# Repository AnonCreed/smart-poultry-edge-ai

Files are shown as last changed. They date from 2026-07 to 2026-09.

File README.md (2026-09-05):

# Edge-AI Based Predictive Closed Control System for Smart Poultry Farming






**Minor Project** -- Department of Electronics and Computer Engineering,
Thapathali Campus, Institute of Engineering (IOE), Tribhuvan University.
Submitted in partial fulfillment of the Bachelor's degree in Electronics,
Communication and Information Engineering (August 2026), under the
supervision of **Er. Anup Shrestha**, by Amir Bhattarai, Aviral Adhikari,
Balram Sharma Kandel, and Bikash BK.

## About

Poultry farming is a major part of Nepal's agricultural sector, and most
farms still run open-house systems where the indoor environment tracks
whatever the weather outside is doing. During the brooding stage (the first
two weeks after hatching) chicks are especially sensitive to temperature
swings, humidity, and ammonia buildup from droppings -- conditions farmers
today mostly manage by manual observation and experience, which means
unfavorable changes can go unnoticed until they've already hurt the flock.

This project came out of discussions around the bird-flu outbreaks in Nepal
in 2026. Actually detecting or preventing disease was out of scope for a
minor project, but keeping a poultry house's environment inside a safe band
is a problem we could tackle directly: continuous IoT sensing, an on-device
ML model that forecasts where temperature and ammonia are heading (not just
where they are), and automated fan/heater control that reacts before a
threshold is crossed rather than after.

That's what this repository is: the full system, not just the dashboard --

- **`hardware/esp32/`** -- an ESP32 sensor node reading temperature, humidity
  and ammonia (DHT11 + MQ-137), driving the fan/heater relays.
- **`hardware/esp32s3_master/`** -- an ESP32-S3 master node that receives
  those readings over ESP-NOW and runs an on-device TFLite Micro model to
  forecast the next reading and flag an ammonia-spike probability, before
  handing everything to the backend.
- **`hardware/kicad/`** -- the KiCad schematic and PCB for the sensor node.
- **`telemetry/`** -- the Django backend: ingestion API, server-side rule
  classifier, and the live dashboard (charts, actuator control, console
  feed, historical export).
- **`docs/`** -- the written report and the proposal/final defense decks
  submitted for the degree.

See [Documentation & Reports](#documentation--reports) for the full report
and defense decks, and [Designs](#designs) for the PCB.

## System at a glance

Django backend, Edge-AI-ready JSON REST API, server-side environmental
classifier, a two-board ESP-NOW hardware pipeline (ESP32 sensor node +
ESP32-S3 master node running an on-device TFLite Micro forecast/spike
model), a standalone sensor simulator for development without hardware, and
a standard Bootstrap 5 dashboard (dual-line forecast charts, actuator
control, live console feed, historical reports/CSV export; Bootstrap and
Chart.js are both vendored locally for air-gapped operation).

## Architecture

```
sensor_simulator.py  ──HTTP POST──>  /api/telemetry/submit/
   (Virtual sensor,                     │ validate -> classify -> persist
    5 s cadence,                        ▼
    random walk +               PoultryTelemetry (SQLite, indexed timestamp)
    anomaly injection)                  │
                                        ▼
dashboard (browser)  ──HTTP GET──>  /api/telemetry/historical/?hours=N
   (5 s polling loop feeds metrics grid, charts, audit log)
```

Physical hardware replaces the simulator with a two-board pipeline (the
Django/dashboard side above is unchanged either way):

```
hardware/esp32/ (DevKit V1, sensor node)  --ESP-NOW-->  hardware/esp32s3_master/ (ESP32-S3, master node)
   DHT11 + MQ-137 + fan/heater                     TFLite Micro forecast + spike model
              ^                                              |
              `------------ ESP-NOW (classification) <-------'  --WiFi/HTTP--> /api/telemetry/submit/
```

The master node is the only board that talks to Django; the sensor node only
ever exchanges fixed-size binary structs with the master over ESP-NOW. See
`hardware/esp32/README.md` and `hardware/esp32s3_master/README.md` for the full pipeline,
wiring, and the MAC-address pairing procedure the two boards need before
they can talk to each other.

| Component | Path |
|---|---|
| Data model + classification enum | `telemetry/models.py` |
| Pure classifier decision framework + spike-risk threshold | `telemetry/classifier.py` |
| API views (submit / historical) + dashboard shell | `telemetry/views.py` |
| URL map | `telemetry/urls.py`, `config/urls.py` |
| Virtual sensor client (dev/demo, no hardware needed) | `sensor_simulator.py` |
| ESP32 sensor-node firmware (DHT11 + MQ-137, ESP-NOW, actuator loop) | `hardware/esp32/src/main.cpp`, `hardware/esp32/include/config.h` |
| ESP32-S3 master-node firmware (ESP-NOW receive, TFLite Micro inference, WiFi/HTTP to Django) | `hardware/esp32s3_master/src/main.cpp`, `hardware/esp32s3_master/include/config.h` |
| Dashboard template | `telemetry/templates/telemetry/dashboard.html` |
| Console stylesheet / client runtime | `telemetry/static/telemetry/dashboard.css`, `dashboard.js` |
| Unit tests (classifier + API + forecast + spike-risk contracts) | `telemetry/tests.py` |

## Classifier rules (first match wins)

1. `ammonia_level > 15.0` -> `CRITICAL_AMMONIA` (dark red background, white text)
2. `temperature > 35.0` (live reading OR the Edge-AI forecast alone) -> `HEAT_STRESS_WARNING` (orange border, orange text) -- no humidity condition
3. `temperature < 18.0` -> `LOW_TEMP_ALERT` (deep blue text, light blue accents)
4. otherwise -> `OPTIMAL_ENVIRONMENT` (charcoal grid, solid green indicator dot)

Classification is computed server-side at ingestion, before the INSERT, so every
stored row is complete and immutable. Thresholds are exposed in the historical
API response so the front end never hardcodes them.

## API

`POST /api/telemetry/submit/`
```json
{
  "temperature": 29.4,
  "humidity": 61.2,
  "ammonia_level": 8.7,
  "predicted_temperature": null,
  "predicted_ammonia": null,
  "predicted_spike_probability": null
}
```
Returns `201` with the persisted record including `predicted_class`.

Forecast channels (`predicted_temperature`, `predicted_ammonia`,
`predicted_spike_probability`) are optional and nullable: absent key, explicit
null, and numeric value are all accepted, since the ESP32-S3 master node may not
be linked yet. When numeric, `predicted_temperature`/`predicted_ammonia` are
bounds-checked against the same physical envelope as their live counterparts,
and `predicted_spike_probability` (the master's TFLite Micro spike-classifier
output) is bounds-checked to `[0, 1]`. All three serialize back as JSON null
when absent, so chart clients can rely on key presence. Classification is
always driven by live readings only; forecasts and spike risk are advisory
overlays. Payloads with missing live fields, non-numeric values, or readings
outside physical/probability envelopes are rejected with `400`.

`GET /api/telemetry/historical/?hours=24`
Returns records in the trailing window, ascending chronologically, plus the active
threshold set — ready for direct ingestion by chart libraries.

## Running the system

Two terminals.

Terminal 1 — backend and dashboard:
```bash
pip install -r requirements.txt
python manage.py migrate
python manage.py runserver 0.0.0.0:8000
# Dashboard (this machine):  http://127.0.0.1:8000/
# Dashboard (other devices, e.g. a phone on the same WiFi): http://<this-machine's-LAN-IP>:8000/
```

Binding `0.0.0.0` (not the default `127.0.0.1`) matters if you're using the
physical ESP32-S3 master node -- it needs to reach this over WiFi, and it
finds the LAN IP itself via UDP broadcast discovery (see
`hardware/esp32s3_master/README.md`), so there's no IP to hardcode on either
side. `ALLOWED_HOSTS` is left open (`"*"`) in `config/settings.py` for the
same reason -- this is a dev-only server, never expose it beyond a trusted
LAN.

Terminal 2 — virtual sensor:
```bash
python sensor_simulator.py
# Edge-AI forecast emulation is ON by default so the KPI forecast lines,
# dashed chart series, console (Pred: ...) markers, and the AI spike-risk
# card all have live numbers. To transmit null forecasts/spike-risk
# (matching the deployment state before the ESP32-S3 master node is linked):
python sensor_simulator.py --no-edge-ai
```

The simulator transmits every 5 seconds using an Ornstein-Uhlenbeck-style random
walk (Gaussian step + mean reversion) per channel, and superimposes two anomaly
generators: a triangular thermal spike exceeding 37 C every 2 minutes, and an
ammonia accumulation ramp that climbs past 30 PPM until a simulated ventilation
fan engages and extracts it back to baseline.

## Tests

```bash
python manage.py test telemetry
```

Covers classifier rule precedence (ammonia dominance, heat-stress from live
reading or forecast alone, low-temperature boundary), ingestion validation,
nullable forecast-channel contracts (absent key, explicit null, populated,
invalid type), and historical ordering/threshold contracts.

## Hardware firmware (two boards: ESP32 sensor node + ESP32-S3 master node)

Two firmware projects ship the physical pipeline; both must be flashed and
paired (by MAC address) for the hardware to work end-to-end.

- **`hardware/esp32/`** -- ESP32 DevKit V1 sensor node. Reads DHT11 on GPIO4 and
  MQ-137 on GPIO34 every 5 s, and sends the readings over **ESP-NOW** to the
  master node (no HTTP, no JSON on this board). Drives an ON/OFF fan relay
  (GPIO32) and an ON/OFF heater relay (GPIO25) from the classification the
  master relays back. See `hardware/esp32/README.md` for the pin map and
  MQ-137 calibration
  procedure.
- **`hardware/esp32s3_master/`** -- ESP32-S3 master node. Receives sensor readings
  over ESP-NOW, runs an on-device TFLite Micro model to forecast the next
  temperature/ammonia reading and an ammonia-spike probability, then POSTs
  the combined record to Django using the same JSON contract the Python
  simulator uses. Relays Django's classification back to the sensor node
  over ESP-NOW. See `hardware/esp32s3_master/README.md` for the model details, the
  Arduino IDE flashing steps, and the MAC-pairing procedure required before
  either board can talk to the other.

Quickstart (flash the master first -- you need its printed MAC address to
configure the sensor node):
```bash
cd hardware/esp32s3_master
# Arduino IDE: install libraries per README.md, edit config_master.h
# (WIFI_SSID, WIFI_PASSWORD, API_BASE_URL, SENSOR_NODE_MAC_ADDR),
# then upload esp32s3_master.ino and note the printed "Receiver MAC".

cd ../esp32
# Edit include/config.h: WIFI_SSID, WIFI_PASSWORD (same network as the
# master), MASTER_MAC_ADDR (from the step above).
pio run                 # Compile
pio run -t upload       # Flash over USB
pio device monitor      # Serial diagnostics at 115200 baud
# Copy this board's printed MAC back into hardware/esp32s3_master/config_master.h's
# SENSOR_NODE_MAC_ADDR and reflash the master.
```

The virtual simulator and the physical firmware pipeline are contract-
compatible: both ultimately POST the same JSON payload shape to Django, so
the backend and dashboard cannot tell them apart. The Python simulator
remains useful for CI, demos, and development without hardware in the loop.

## Views

Two tab-switched views share a single polling loop, so the console tail
accumulates in the background even while the user is on the Overview.

### Overview Dashboard
- KPI cards: instantaneous readings with desaturated state accents (colored
  value text plus a 2px left-border highlight; backgrounds stay untouched).
  Each forecastable channel shows a muted secondary line beneath the primary
  value: `AI Forecast: 27.8 degC`, `AI Forecast: 8.4 ppm`. When the ESP32-S3
  master node's link is inactive the line reads `AI Forecast: pending`.
- **AI spike risk** card: the ESP32-S3 master node's TFLite Micro spike-
  classifier probability, rendered as a percentage. Escalates
  ok -> warn -> crit as the probability crosses the calibrated threshold
  (echoed from the API, never hardcoded twice) and twice that threshold.
  Reads `Master node: pending` until the master node is linked.
- Dual-line charts (full vertical breathing room): solid stroke for live
  sensor data, dashed light stroke for Edge-AI forecasts (`spanGaps: false`,
  so null forecast points render as gaps and a fully-null channel is simply
  invisible while remaining mounted), plus a dashed threshold baseline.

### System Logs Feed
Dedicated full-page console. Append-only tail keyed by record id; each new
ingestion appends one line in the format
`[YYYY-MM-DD HH:MM:SS] INGESTION SUCCESS -> T: 27.4C (Pred: 27.8C) | RH: 60.2% | NH3: 8.1ppm (Pred: 8.4ppm) | STATE: OPTIMAL | SPIKE_RISK: 14%`
with text tinted by classification. When a forecast channel is null the
inline marker reads `(Pred: n/a)`; the `SPIKE_RISK` segment is omitted
entirely (not `n/a`) when the master node hasn't reported a probability yet.
Includes a rolling 200-line buffer and a pause-scroll control. The server
emits the same line via the `telemetry.ingest` logger, so `journalctl` and
the browser can be cross-referenced without translation.

## Designs

KiCad schematic + PCB for the ESP32 sensor node live in `hardware/kicad/`
(`kicad.kicad_pro`, `.kicad_sch`, `.kicad_pcb`, `.kicad_prl` -- open the
`.kicad_pro` in KiCad 9). It lays out the ESP32 DevKit V1 footprint alongside
the DHT11, MQ-137, fan/heater relay drive, and terminal-block wiring
described in `hardware/esp32/README.md`.

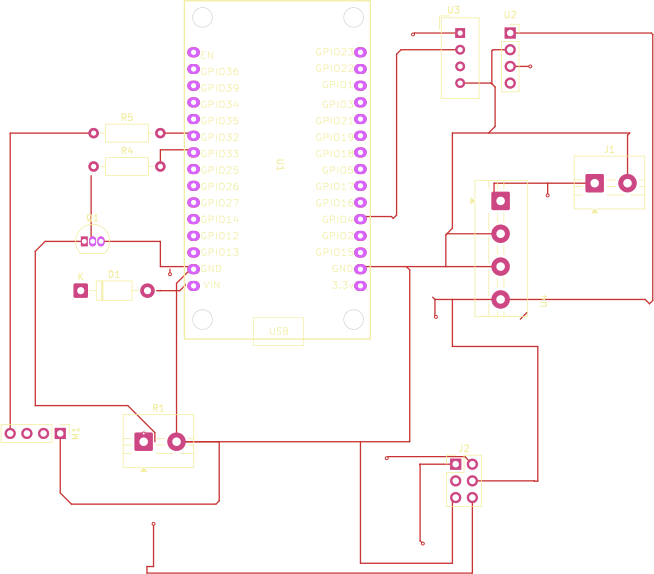
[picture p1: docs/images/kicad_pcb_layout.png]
KiCad PCB top-copper layout


## Documentation & Reports

| Document | Path |
|---|---|
| Minor project report (full, 81 pages) | [`docs/minor_project_report.pdf`](docs/minor_project_report.pdf) |
| Proposal presentation | [`docs/presentations/proposal_presentation.pdf`](docs/presentations/proposal_presentation.pdf) |
| Final defense presentation | [`docs/presentations/final_presentation.pdf`](docs/presentations/final_presentation.pdf) |
| Hardware & firmware architecture deep-dive | [`HARDWARE_DOCUMENTATION.md`](HARDWARE_DOCUMENTATION.md) |

## Team

| Name | Roll No. |
|---|---|
| Amir Bhattarai | THA080BEI005 |
| Aviral Adhikari | THA080BEI011 |
| Balram Sharma Kandel | THA080BEI012 |
| Bikash BK | THA080BEI015 |

Supervised by **Er. Anup Shrestha**, Department of Electronics and Computer
Engineering, Thapathali Campus, Institute of Engineering, Tribhuvan University.

## License

MIT -- see [`LICENSE`](LICENSE).

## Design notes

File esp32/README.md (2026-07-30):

# ESP32 Sensor Node -- Firmware

Production-grade Arduino/ESP32 firmware for the Poultry Telemetry sensor
node. Reads DHT22 (temperature + humidity) and MQ-137 (ammonia PPM) every
5 seconds and sends them over **ESP-NOW** to the ESP32-S3 master node
(`../esp32s3_master/`), which runs the on-device forecast/spike model and
owns the WiFi/HTTP leg to Django. The master relays Django's classification
back over ESP-NOW so this board can still drive its own fan and heater PWM
outputs, closing the control loop end-to-end across the two boards.

This board still joins WiFi (see `include/config.h`), but only to (a) land
on the same channel as the master -- ESP-NOW requires both peers on the
same channel, and joining the same AP is the simplest way to guarantee that
-- and (b) sync wall-clock time over NTP for the model's hour/month cyclic
features. It no longer POSTs to Django directly; see
`../esp32s3_master/README.md` for the full two-board pipeline and the MAC
pairing procedure required before either board can talk to the other.

## Pin map (must match the KiCad schematic)

| Signal | GPIO | Socket pin | Notes |
|---|---|---|---|
| `DHT_DATA` | GPIO4  | 20 | 10 kOhm pull-up to 3V3; single-wire DHT22 protocol |
| `MQ_DATA` | GPIO34 | 12 | INPUT-ONLY, ADC1_CH6 -- required so WiFi and ADC coexist |
| `PWM_FAN` | GPIO32 | 10 | LEDC ch 0, 25 kHz -- gate driven through R5 = 200 Ohm |
| `PWM_HEATER`  | GPIO33 | 9 | LEDC ch 1, 25 kHz -- gate driven through R4 = 200 Ohm |
| `VIN` (+5V) | - | 1 | USB or external 5 V bench supply |
| `GND` | - | 2 / 17 | Common ground with sensor and actuator returns |
| `3V3` | - | 16 | Sensor Vcc supply |

Two constraints are non-negotiable:

1. **MQ-137 output must be scaled to 0-3.3 V before reaching GPIO34.** MQ
   modules commonly swing to 5 V; feeding that directly into any ESP32 pin
   damages the SoC. Use an on-module divider or add an external 1:2 divider
   (e.g. 10 kOhm / 20 kOhm to GND).
2. **GPIO34 is input-only.** It has no internal pull-ups and cannot be an
   output. Any attempt to move `MQ_DATA` to a different pin also invalidates
   the "ADC1 while WiFi is active" guarantee -- ADC2 channels are unusable
   during WiFi association.

## Build and flash

```bash
cd esp32
# Edit include/config.h: WIFI_SSID, WIFI_PASSWORD, MASTER_MAC_ADDR
# (see the MAC pairing procedure in ../esp32s3_master/README.md), and
# GMT_OFFSET_SEC for your timezone.
pio run                 # Compile
pio run -t upload       # Flash over USB
pio device monitor      # Serial console at 115200 baud
```

Flash the ESP32-S3 master (`../esp32s3_master/`) first so you have its MAC
address to put in `MASTER_MAC_ADDR` before flashing this board.

Alternatively in the Arduino IDE: open `src/main.cpp` as `main.ino` (or copy
into a sketch with the same name as the folder), install the two libraries
listed in `platformio.ini` (ESP-NOW ships with the esp32 board package, no
separate library needed), and select "ESP32 Dev Module".

## MQ-137 calibration

The datasheet curve fit ships in `config.h` (`MQ137_A = 102.2`, `MQ137_B =
-2.473`), but `MQ137_R0_KOHMS` **must be recalibrated per unit** after a 24-48
hour burn-in:

1. Power the sensor continuously in known-clean outdoor air for at least 24 h.
2. Read the averaged Rs value from the serial log (raw `[MQ] Rs=...` line
   after uncommenting the diagnostic printf near `mqCountsToPpm`).
3. Set `MQ137_R0_KOHMS` to that value.
4. Reflash.

Without this step the reported PPM has a per-unit multiplicative error that
can easily reach 3-5x. The classifier threshold (25 PPM CRITICAL) is set
against calibrated readings, so uncalibrated sensors will either false-alarm
or, worse, miss real breaches.

## Control loop

The master node POSTs each record to Django, which classifies it and
returns `record.predicted_class`. The master relays that string back to
this board over ESP-NOW (`ActuatorCommand`), and the firmware maps it to
actuator state:

| Classification | Fan  | Heater |
|---|---|---|
| `CRITICAL_AMMONIA` | ON | OFF |
| `HEAT_STRESS_WARNING` | ON | OFF |
| `LOW_TEMP_ALERT` | OFF  | ON |
| `OPTIMAL_ENVIRONMENT` | OFF  | OFF |

The interlock (fan and heater never both on) is inherent to the
classification -- a single state is returned per record.

## Edge-AI forecast and spike-risk prediction

This board no longer computes a forecast itself -- the on-node linear-
extrapolation stub from earlier versions has been superseded by the ESP32-S3
master's real TFLite Micro model, which produces `predicted_temperature`,
`predicted_ammonia`, and `predicted_spike_probability` from a rolling window
of this board's raw readings. See `../esp32s3_master/README.md` for the
model details and the spike-risk threshold.

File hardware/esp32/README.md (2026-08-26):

# ESP32 Sensor Node -- Firmware

Production-grade Arduino/ESP32 firmware for the Poultry Telemetry sensor
node. Reads DHT11 (temperature + humidity) and MQ-137 (ammonia PPM) every
5 seconds and sends them over **ESP-NOW** to the ESP32-S3 master node
(`../esp32s3_master/`), which runs the on-device forecast/spike model and
owns the WiFi/HTTP leg to Django. The master relays Django's classification
back over ESP-NOW so this board can still drive its own fan (PWM speed
control) and PTC heater (ON/OFF relay -- see `HEATER_RELAY_ON`/`_OFF` in
`include/config.h` for this board's relay polarity), closing the control
loop end-to-end across the two boards.

This board has **no WiFi at all** -- no credentials, no AP join, no IP, no
NTP. It only brings the radio up to speak ESP-NOW directly to the master,
on a fixed channel set at compile time (`ESPNOW_WIFI_CHANNEL`,
`include/config.h`) since there's no AP association to inherit a channel
from. See `include/config.h`'s "Radio" section for why the channel is
fixed rather than negotiated, and what to do if it ever needs to change.
This board never talks to Django directly either; see
`../esp32s3_master/README.md` for the full two-board pipeline and the MAC
pairing procedure required before either board can talk to the other.

## Pin map (must match the KiCad schematic)

| Signal | GPIO | Socket pin | Notes |
|---|---|---|---|
| `DHT_DATA` | GPIO4  | 20 | 10 kOhm pull-up to 3V3; single-wire DHT11 protocol |
| `MQ_DATA` | GPIO34 | 12 | INPUT-ONLY, ADC1_CH6 -- required so WiFi and ADC coexist |
| `PWM_FAN` | GPIO32 | 10 | LEDC PWM (channel 0, 25 kHz, 8-bit) speed target to the fan's own driver IC -- not a power switch, see `FAN_ENABLE` below |
| `FAN_ENABLE`  | GPIO27 | TBD -- verify against schematic | Digital output gating an external N-MOSFET on the fan's GND leg; HIGH = fan powered, LOW = de-energized. Real hard-off, since many cheap fans don't honor 0% PWM duty as a true stop |
| `HEATER_RELAY`| GPIO25 | TBD -- verify against schematic | Digital output to relay module IN pin; HIGH = heater ON, LOW = OFF (`HEATER_RELAY_ON`/`_OFF` in `config.h` -- confirmed by bench test 2026-08-23, opposite of the module's original active-LOW assumption). ON/OFF only, no speed control |
| `LCD_SDA` | GPIO21 | TBD -- verify against schematic | I2C data to the LCD's PCF8574T backpack. ESP32 DevKit V1 hardware I2C default |
| `LCD_SCL` | GPIO22 | TBD -- verify against schematic | I2C clock to the LCD's PCF8574T backpack. ESP32 DevKit V1 hardware I2C default |
| `VIN` (+5V) | - | 1 | USB or external 5 V bench supply; also feeds the LCD's VCC |
| `GND` | - | 2 / 17 | Common ground with sensor and actuator returns, and the LCD |
| `3V3` | - | 16 | Sensor Vcc supply |

Two constraints are non-negotiable:

1. **MQ-137 output must be scaled to 0-3.3 V before reaching GPIO34.** MQ
   modules commonly swing to 5 V; feeding that directly into any ESP32 pin
   damages the SoC. Use an on-module divider or add an external 1:2 divider
   (e.g. 10 kOhm / 20 kOhm to GND).
2. **GPIO34 is input-only.** It has no internal pull-ups and cannot be an
   output. Any attempt to move `MQ_DATA` to a different pin also invalidates
   the "ADC1 while WiFi is active" guarantee -- ADC2 channels are unusable
   during WiFi association.

## Build and flash

```bash
cd hardware/esp32
# Edit include/config.h: MASTER_MAC_ADDR (see the MAC pairing procedure in
# ../esp32s3_master/README.md) and ESPNOW_WIFI_CHANNEL if your router isn't
# on channel 1. No WiFi credentials to set -- this board has none.
pio run                 # Compile
pio run -t upload       # Flash over USB
pio device monitor      # Serial console at 115200 baud
```

Flash the ESP32-S3 master (`../esp32s3_master/`) first so you have its MAC
address to put in `MASTER_MAC_ADDR` before flashing this board.

Alternatively in the Arduino IDE: open `src/main.cpp` as `main.ino` (or copy
into a sketch with the same name as the folder), install the two libraries
listed in `platformio.ini` (ESP-NOW ships with the esp32 board package, no
separate library needed), and select "ESP32 Dev Module".

## MQ-137 calibration

The datasheet curve fit ships in `config.h` (`MQ137_A = 102.2`, `MQ137_B =
-2.473`), but `MQ137_R0_KOHMS` **must be recalibrated per unit** after a 24-48
hour burn-in:

1. Power the sensor continuously in known-clean outdoor air for at least 24 h.
2. Read the averaged Rs value from the serial log (raw `[MQ] Rs=...` line
   after uncommenting the diagnostic printf near `mqCountsToPpm`).
3. Set `MQ137_R0_KOHMS` to that value.
4. Reflash.

Without this step the reported PPM has a per-unit multiplicative error that
can easily reach 3-5x. The classifier threshold (15 PPM CRITICAL) is set
against calibrated readings, so uncalibrated sensors will either false-alarm
or, worse, miss real breaches.

## Control loop

The master node POSTs each record to Django, which classifies it and
returns `record.predicted_class`. The master relays that string back to
this board over ESP-NOW (`ActuatorCommand`), along with **two independently
computed bytes**: `fan_pwm` (0-255, from its on-device model's
predicted-NH3 error) and `heater_pwm` (0-255, from the classification --
`LOW_TEMP_ALERT` -> 255, else 0). A dashboard MANUAL override, if set,
replaces *both* bytes with the operator's fan speed % / heater power %
before they're sent. This board makes no actuation decisions of its own any
more -- it only applies whatever the master sends:

| Signal | Fan (PWM) | Heater relay |
|---|---|---|
| `fan_pwm` | Written verbatim as PWM duty (0-255) | -- |
| `fan_pwm > 0` | `FAN_ENABLE` driven HIGH (powered) | -- |
| `fan_pwm == 0`  | `FAN_ENABLE` driven LOW (de-energized) | -- |
| `heater_pwm > 0`| -- | ON (relay energized) |
| `heater_pwm == 0`| -- | OFF (relay de-energized) |

**Note:** earlier revisions of this board guaranteed fan and heater were
never both ON, since a single classification string drove both locally.
That guarantee no longer holds -- `fan_pwm` and `heater_pwm` are computed
independently on the master (and either can come from a MANUAL dashboard
override, decoupled from the other), so e.g. a nonzero MANUAL fan override
alongside a nonzero heater_pwm (MANUAL or `LOW_TEMP_ALERT`-driven) will run
the fan and energize the heater relay simultaneously. If that combination is
unsafe for the physical setup, it needs to be enforced explicitly (either
server-side in the dashboard/master's `loop()`, or by forcing `fan_pwm` to 0
in this board's `applyActuators()` whenever `heaterOn` is true) -- it is not
currently enforced anywhere in either firmware.

## Edge-AI forecast and spike-risk prediction

This board no longer computes a forecast itself -- the on-node linear-
extrapolation stub from earlier versions has been superseded by the ESP32-S3
master's real TFLite Micro model, which produces `predicted_temperature`,
`predicted_ammonia`, and `predicted_spike_probability` from a rolling window
of this board's raw readings. See `../esp32s3_master/README.md` for the
model details and the spike-risk threshold.

## LCD (I2C 16x2, RG1602A-IIC(P) / PCF8574T backpack)

Wired to the DevKit's hardware I2C bus (`include/config.h`: `PIN_LCD_SDA` =
GPIO21, `PIN_LCD_SCL` = GPIO22; GND to GND, VCC to VIN/5V). Shows a static
two-line readout of this board's own current reading -- no rotation, no
forecast:

- **Row 0** -- current temperature + humidity from the DHT11 (`T:25.3C H:60%`).
- **Row 1** -- current MQ-137 ammonia reading (`NH3: 12.3 ppm`).

Both rows redraw every time a fresh sample completes (`SAMPLE_INTERVAL_MS`,
5 s by default); before the first successful reading they show a boot
placeholder instead. The master still relays back `predicted_temperature`/
`predicted_ammonia`/`has_prediction` on the `ActuatorCommand` wire contract
(see the comment above `struct ActuatorCommand` in `src/main.cpp`) -- this
board receives them but intentionally doesn't display them; the LCD is
current-data-only on this branch.

The backpack answers at I2C address `0x27` by default (`LCD_I2C_ADDR` in
`config.h`); some PCF8574AT clones use `0x3F` instead -- if the display stays
blank after wiring is confirmed correct, run an I2C scanner sketch to find
the real address before assuming a wiring fault. Requires the
`marcoschwartz/LiquidCrystal_I2C` library, pulled automatically via
`platformio.ini`'s `lib_deps`.

## Benchmark mode -- synthetic data for testing the predictive system

`platformio.ini` defines a second environment, `esp32dev_benchmark`, that
replaces this board's real DHT11/MQ-137 reads with a scripted sequence of
scenarios instead -- for exercising the master's on-device predictive model,
Django's classifier, and the real actuator response on-demand and
repeatably, without needing a physical sensor attached or waiting on real
environmental drift to test an edge case. Everything downstream of the
sensor read is the genuine pipeline: real ESP-NOW, real TFLite inference on
the master, real classification, real fan/heater relay -- only the sensor
value itself is synthetic.

```bash
pio run -e esp32dev_benchmark -t upload    # flash the benchmark build
pio device monitor                         # watch [BENCHMARK]/[TX] lines

# ... test, watch the master's [MODEL]/[ACTUATE] lines and the dashboard ...

pio run -e esp32dev -t upload              # flash back to real sensors
```

This is **compile-time only** (`BENCHMARK_MODE`, set via the dedicated
environment's `build_flags`, never a runtime toggle) -- a board can't
accidentally start reporting fake data without an explicit reflash, and both
the boot banner and the LCD say "BENCHMARK MODE" loudly on startup as a
physical reminder while it's active.

The scenario list (`BENCHMARK_SCENARIOS` in `src/main.cpp`) cycles through,
holding or ramping each for `BENCHMARK_SAMPLES_PER_SCENARIO` samples
(`config.h`, default 24 * 5 s = 2 minutes per scenario). **Note:** this
2-minute-per-scenario default predates the current model's retrain -- the
old windowed model warmed up in ~9 samples (~45 s), so 2 minutes was
generous. The retrained model needs 7 finalized 10-minute buckets
(~70 minutes after boot, see `hardware/esp32s3_master/README.md`'s "Model
architecture" section) before it produces its first prediction at all, so
a full benchmark loop now cycles through several scenarios before any
prediction appears. Fine for exercising ESP-NOW/classification/actuation
(none of that depends on warm-up), but if you specifically want to watch
`predicted_ammonia` lead a live reading during `AMMONIA_RAMP_TO_SPIKE`,
either let one scenario hold well past 70 minutes (raise
`BENCHMARK_SAMPLES_PER_SCENARIO` for that run) or just wait out the real
warm-up once and watch subsequent scenarios normally after that.

| Scenario | Tests |
|---|---|
| `OPTIMAL_BASELINE` | Warm-up baseline; nothing should trip. |
| `AMMONIA_STEP_CRITICAL` / `_RECOVER` | Instant step across the 15 ppm `CRITICAL_AMMONIA` threshold, both directions -- classification latency, actuator response speed. |
| `AMMONIA_RAMP_TO_SPIKE` / `_RECOVER` | Gradual rise/fall through the threshold -- does `predicted_ammonia` (the forecast) lead the live reading, and does `predicted_spike_probability` rise before the classifier actually flips? |
| `AMMONIA_BOUNDARY_LOW` / `_HIGH` | Held just under/over 15 ppm -- exact threshold correctness, no off-by-one. |
| `HEAT_STRESS_STEP` / `_RECOVER` | T + RH combined past both thresholds at once (the classifier's conjunction rule) and back. |
| `LOW_TEMP_STEP` / `_RECOVER` | Below 18°C and back -- heater relay reactivity. |
| `COLD_AND_CRITICAL_AMMONIA` / `_RECOVER` | Cold and critical ammonia at once -- `predicted_class` comes back `CRITICAL_AMMONIA` only (classify_environment() checks ammonia first), so this is the regression case for the `low_temperature_alert` fix: both fan **and** heater must activate, not just the fan. |

Add, remove, or edit entries in `BENCHMARK_SCENARIOS` for other cases (a
different profile's thresholds, a slower/faster ramp, a longer soak at one
value) -- each row is just a name plus a start/end value per channel, so a
constant scenario is a step and a `Start != End` scenario is a ramp.

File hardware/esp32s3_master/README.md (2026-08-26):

# ESP32-S3 Master Node -- Firmware

Receives raw sensor samples from the ESP32 DevKit V1 sensor node
(`hardware/esp32/`) over ESP-NOW, runs an on-device TFLite Micro model to forecast
next-tick temperature/ammonia and an ammonia-spike probability, forwards the
combined record to the Django backend, and relays the resulting
classification back to the sensor node so it can drive its own actuators.

```
esp32 (DevKit V1)  --ESP-NOW-->  esp32s3_master (this board)  --WiFi/HTTP-->  Django
   sensors + fan/heater              inference + relay              /api/telemetry/submit/
        ^                                    |
        `------------ ESP-NOW (classification) <----------'
```

Builds with PlatformIO (same toolchain as the sensor node in `hardware/esp32/`).

## Contents

| File | Purpose |
|---|---|
| `src/main.cpp` | ESP-NOW receive, WiFi/HTTP forward to Django, actuator relay. |
| `src/model_runner.cpp` / `include/model_runner.h` | Feature engineering, TFLite Micro inference, output scaling. |
| `include/model_data.h` | Trained TFLite Micro model, flatbuffer byte array. **Trained artifact -- do not hand-edit.** |
| `include/scaler_params.h` | Feature normalization (mean/scale) and the calibrated spike-risk decision threshold. **Trained artifact -- do not hand-edit.** |
| `include/config.h` | Django API port/path, discovery protocol constants, NTP, timing constants. No IP to edit -- see Discovery below. |
| `include/credentials.h` (gitignored, copy from `.example`) | WiFi SSID/password. |

## Model architecture (retrained 2026-08-26)

A bifurcated multi-task MLP (Keras) trained offline against
`poultry_sensor_data_cleaned.csv` (9,708 rows), replacing the earlier
windowed model:

- **Input**: a flat 44-element engineered feature vector -- no on-device
  windowed tensor. The "sliding window" lives entirely in feature
  engineering (pandas `.shift()`/`.rolling()` at training time,
  `buildFeatureRow()` in `model_runner.cpp` on-device): 6 base columns
  (`temperature`, `humidity`, `ammonia_ppm`, `hour_sin`, `hour_cos`,
  `temp_hum_interaction`) x 7 derived values each (`lag1`, `lag2`, `lag3`,
  `lag6`, `roll_mean3`, `roll_std3`, `delta1`) = 42, plus `ammonia_accel`
  (second-order ammonia momentum) and `week` (flock age in weeks, clipped
  to `[1, 5]`) = 44 total. Exact order is fixed by `feature_cols` in the
  training script and mirrored feature-for-feature in `buildFeatureRow()`.
- **Output**: two 2-element heads --
  `next_values` (regression: standardized next-tick temperature and
  log1p-transformed next-tick ammonia, both needing the inverse transform
  in `readPrediction()`) and `spike_flags` (classification: sigmoid
  ammonia-spike and temperature-spike probabilities). TFLite conversion
  does **not** guarantee output tensor order matches the Python
  `outputs=[...]` declaration order -- `readPrediction()` disambiguates at
  runtime via a value-range heuristic (sigmoid outputs stay in `[0, 1]`;
  standardized regression outputs don't), documented in-line with the exact
  verification snippet, with a fallback to the empirically verified fixed
  order if that heuristic is ever ambiguous.
- **Training cadence vs. real sensor cadence**: the training pipeline
  resamples to a fixed 10-minute interval, but the sensor node transmits
  every ~5 s (`SAMPLE_INTERVAL_MS`, matching this project's
  `HARDWARE_DOCUMENTATION.md` / report Section 5.5.6). Feeding raw 5s
  samples straight into "lag1" would silently redefine it from "10 minutes
  ago" to "5 seconds ago" and make every learned weight meaningless.
  `model_runner.cpp` bridges this by averaging incoming samples into a
  rolling 10-minute `Bucket`, finalizing it into a `FinalizedBucket` history
  ring buffer (7 deep -- lag6 reaches 60 min back, plus the current bucket)
  once `kBucketDurationMs` elapses, and computing all lag/rolling/delta
  features only from that finalized-bucket history. Consequence: the first
  real inference doesn't happen until **~70 minutes after boot** (7 buckets
  x 10 min), during which `[MODEL] warming up` prints instead.
- **Export format -- must stay pure float32, not quantized**: an earlier
  export used `tf.lite.TFLiteConverter`'s dynamic-range quantization
  (`converter.optimizations = [tf.lite.Optimize.DEFAULT]`), which produced
  a smaller `.tflite` (~19 KB vs ~49 KB) that ran fine on a desktop
  `tf.lite.Interpreter` but made TFLite Micro's `Invoke()` silently
  overwrite the input tensor with NaN on real hardware -- confirmed by
  Serial-printing the input tensor's values immediately before and after
  `Invoke()` (finite before, all-NaN after), isolating the corruption to
  the embedded kernel's handling of hybrid-quantized `FULLY_CONNECTED`
  weights rather than any host-side bug. Fix: re-export from the saved
  `.keras` model with no `converter.optimizations` set at all. **Any future
  retrain must export the same way** (see below) or this bug reappears.

## Swapping in a retrained model

`model_data.h` and `include/scaler_params.h` are the only files a retrain
should touch -- regenerate both from the training pipeline's
`export_meta.pkl` + the trained `.tflite`, drop them in place of the
existing ones, and rebuild. Nothing else needs to change **as long as the
new model keeps the same 44-feature input layout and the same two
2-element output heads** described above. If the training pipeline ever
changes which features it derives (`feature_cols` in the training script),
`buildFeatureRow()` in `model_runner.cpp` needs matching edits -- everything
else in that file (bucketing, normalization, tensor plumbing) is generic
and doesn't care what the model looks like.

Steps, in order:

1. Retrain and save the Keras model as usual, then export to TFLite
   **without quantization** (see "must stay pure float32" above):
   ```python
   converter = tf.lite.TFLiteConverter.from_keras_model(model)
   # Deliberately no converter.optimizations -- see README for why.
   tflite_model = converter.convert()
   open('model_esp32.tflite', 'wb').write(tflite_model)
   ```
2. Verify the output tensor order didn't shift:
   ```python
   import tensorflow as tf, numpy as np
   interp = tf.lite.Interpreter(model_path='model_esp32.tflite')
   interp.allocate_tensors()
   inp, out = interp.get_input_details(), interp.get_output_details()
   x = np.zeros((1, 44), dtype=np.float32)
   interp.set_tensor(inp[0]['index'], x); interp.invoke()
   for d in out: print(d['name'], '->', interp.get_tensor(d['index']))
   ```
   If the order changed, `readPrediction()`'s runtime heuristic in
   `model_runner.cpp` should still cope automatically -- but double-check
   its documented fallback order comment matches the new result anyway.
3. Verify the op list didn't grow beyond what `init()`'s
   `MicroMutableOpResolver<3>` registers (`FullyConnected`, `Concatenation`,
   `Logistic`):
   ```python
   from tensorflow.lite.python import schema_py_generated as schema_fb
   buf = bytearray(open('model_esp32.tflite', 'rb').read())
   m = schema_fb.ModelT.InitFromObj(schema_fb.Model.GetRootAsModel(buf, 0))
   codes = {(oc.deprecatedBuiltinCode if oc.builtinCode == 0 else oc.builtinCode) for oc in m.operatorCodes}
   names = {v: k for k, v in vars(schema_fb.BuiltinOperator).items() if isinstance(v, int)}
   print([names.get(c, c) for c in codes])
   ```
   A new op means adding the matching `Add*()` call in `init()` and bumping
   the resolver's template argument.
4. Regenerate `model_data.h` as a C byte array from the `.tflite` file
   (standard `xxd -i` / equivalent one-liner), and `scaler_params.h` from
   `export_meta.pkl`'s `feature_mean`/`feature_scale`/`reg_mean`/
   `reg_scale`/`best_thresholds` -- keep the reg/clf ordering comments in
   that file in sync with `reg_targets`/`clf_targets` from the training
   script.
5. Rebuild, reflash, and confirm on Serial that early inferences (after the
   ~70-minute warm-up) are finite and plausible -- not NaN.

## Flashing

1. Install PlatformIO (CLI or the VS Code extension).
2. Copy `include/credentials.h.example` to `include/credentials.h` and fill
   in `WIFI_SSID` / `WIFI_PASSWORD` for this board's own network -- the
   sensor node has no WiFi credentials of its own to match; it never joins
   any AP (see `../esp32/README.md`). ESP-NOW still requires both radios on
   the same WiFi channel, so the sensor node hardcodes a fixed channel
   (`ESPNOW_WIFI_CHANNEL`, `../esp32/include/config.h`) instead -- if this
   board's router ever assigns a different channel than that constant, this
   board logs a boot-time `[WIFI] WARNING` (it can't fix the mismatch
   itself; update the sensor's config.h and reflash it, or fix the
   router's channel).
3. `pio run -t upload` (or use the PlatformIO IDE build/upload buttons),
   then open the serial monitor at 115200 baud. No Django IP to configure --
   see Discovery below.

## Discovery (no hardcoded Django IP)

This board finds the Django host at runtime instead of using a baked-in IP,
so the same firmware image works unmodified on any WiFi network the board
and the Django PC both join:

1. On boot (and again from `loop()` any time the host is unknown), it
   broadcasts a UDP packet to the local subnet's broadcast address on port
   `DISCOVERY_PORT` (`config.h`).
2. `telemetry/discovery.py` on the Django side listens on that same UDP
   port (started automatically by `manage.py runserver`) and replies to
   whoever sent the request.
3. The board reads the reply's **source IP** as the Django host -- not
   the payload -- so no address is ever hand-configured.
4. If POSTs start failing against a previously-discovered host (e.g. the
   Django PC got a new DHCP lease), the board drops it and re-discovers
   automatically after a few consecutive failures.

Requirements: the Django PC and this board must be on the same subnet
(broadcast doesn't cross routers/VLANs), and `python manage.py runserver`
must be bound to `0.0.0.0:8000` (not `127.0.0.1`) so both the HTTP API and
the discovery responder are reachable from the board.

## MAC pairing

Unlike the sensor node, this board doesn't need a MAC address configured up
front -- `onDataRecv()` in `main.cpp` auto-learns the sensor node's MAC from
the first ESP-NOW packet it receives and registers it as a peer so it can
send `ActuatorCommand`s back.

1. Flash this board first. On boot it prints:
   ```
   [BOOT] Master MAC (WiFi STA): AA:BB:CC:DD:EE:FF
   ```
   Copy that into `hardware/esp32/include/config.h`'s `MASTER_MAC_ADDR` on
   the sensor node.
2. Flash the sensor node (`hardware/esp32/`, see its README). No MAC needs
   copying back the other way -- this board learns it automatically.

## Data flow per sample

1. Sensor node sends a `SensorPacket` (temperature, humidity, ammonia_ppm --
   no hour/month; it has no WiFi/NTP to source them from) over ESP-NOW
   every 5 s. This board supplies hour itself from its own NTP sync
   (`currentHour()` in `main.cpp`) for the model's hour-of-day feature.
2. This board averages incoming samples into a rolling 10-minute bucket and
   keeps a 7-bucket finalized history (`model_runner.cpp`) -- see "Model
   architecture" above for why. That history needs to fill before the first
   inference; expect `[MODEL] warming up` lines for the first ~70 minutes
   after boot.
3. Once warmed up, each bucket finalization runs one inference producing
   `predicted_temperature`, `predicted_ammonia`, and
   `predicted_spike_probability` (ammonia-spike probability; the model also
   computes a `temp_spike_probability` but that isn't wired to Django/the
   dashboard yet). While still warming up, the three POSTed fields are
   `null` and Django classifies from live readings alone.
4. That triple, plus the raw reading, POSTs to
   `http://{DJANGO_HOST}:{DJANGO_PORT}{SUBMIT_PATH}` using the same JSON
   contract the Python simulator and Django's ingestion validation already
   expect (see the project root `README.md`).
5. Django's rule-based classification (`predicted_class`) comes back in the
   response and is relayed to the sensor node over ESP-NOW so it can drive
   its fan/heater -- independent of the spike-risk prediction, which is an
   advisory signal only and never itself flips the classification.
6. The same `ActuatorCommand` also carries `has_prediction` +
   `predicted_temperature` + `predicted_ammonia` (the just-computed
   `pred.temperature_next` / `pred.ammonia_next`, or the last cached
   prediction when this send is the independent MANUAL-override poll rather
   than a fresh inference -- see `g_lastPrediction` in `main.cpp`) purely so
   the sensor node's LCD can show a "Predicted" screen. These three fields
   are display-only; no actuation decision reads them back on either board.

## Spike-risk threshold

`scaler_params.h`'s `kAmmoniaSpikeThreshold` is the calibrated cutoff above
which the model's classifier head predicts an imminent ammonia spike (the
model also has a `kTempSpikeThreshold` for the sibling temperature-spike
head, currently used on-device only -- see "Data flow per sample" above).
Django echoes `kAmmoniaSpikeThreshold`'s value as
`ammonia_spike_risk_threshold` in the `/api/telemetry/historical/` response
(`telemetry/classifier.py`'s `AMMONIA_SPIKE_RISK_THRESHOLD`) so the
dashboard never hardcodes a second copy. If the model is ever retrained
with different thresholds, update both places together.

## Sensor silence watchdog

If no `SensorPacket` arrives over ESP-NOW for `SENSOR_SILENCE_TIMEOUT_MS`
(`config.h`, 3x the sensor's 5s `SAMPLE_INTERVAL_MS` -- ~15s), `loop()`
logs `[ESPNOW] No sensor packet in ... -- re-initializing ESP-NOW.` and
re-runs the same `esp_now_deinit()`/`initEspNow()`/`registerSensorPeer()`
recovery sequence already used when this board's own WiFi reconnects (see
`ensureWifi()`). This covers a stuck ESP-NOW stack that didn't involve a
WiFi drop on this board -- distinct from `postToDjango()`'s existing
3-failures-triggers-re-discovery logic, which reacts to failed HTTP POSTs
to Django, not to sensor silence. Cheap and safe to fire repeatedly: it
doesn't touch the model's bucket history, so a real but brief sensor outage
doesn't cost the ~70 minute warm-up. If the sensor node is genuinely
powered off, this just keeps retrying every window until it comes back --
it can't fix a truly-dead sensor by itself, only re-arm this board's own
side of the link in case that was the actual problem.

## Known limitations

- Single sensor node only: the feature/history buffers assume one upstream
  board. Supporting multiple sensor nodes would need per-node history
  buffers and a node-identity field threaded through the ESP-NOW packet,
  Django's model, and the dashboard -- not implemented here.
- No ESP-NOW encryption -- fine on a private/trusted LAN, not for anything
  internet-facing. See `HARDWARE_DOCUMENTATION.md`'s security section for
  the same caveat on the original HTTP-only design.
- If the Django POST fails (network blip, backend restart), that sample's
  classification never reaches the sensor node and its actuators simply
  hold their last commanded state.
- The sensor node hardcodes its ESP-NOW channel instead of negotiating one
  (see "Flashing" above) -- if the router's channel ever changes, ESP-NOW
  silently breaks until `ESPNOW_WIFI_CHANNEL` is updated and the sensor
  node reflashed. This board logs a warning when it detects the mismatch,
  but can't self-heal it (unlike the silence watchdog above, which only
  helps when this board's own ESP-NOW stack -- not the channel itself --
  is the problem).

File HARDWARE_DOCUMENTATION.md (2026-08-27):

# Hardware & Embedded Firmware Architecture Defense Guide

> **Two-board architecture as of the ESP-NOW revision.** The system is now
> two microcontrollers, not one: an **ESP32 DevKit V1 sensor node**
> (`hardware/esp32/`, unchanged hardware, revised firmware) reads DHT11/MQ-137 and
> sends raw samples over **ESP-NOW** to an **ESP32-S3 master node**
> (`hardware/esp32s3_master/`, new), which runs an on-device TFLite Micro model and
> owns the WiFi/HTTP leg to Django. Everything below that describes the
> single-board HTTP pipeline has been updated to describe the sensor node's
> half only; the master node's half is documented where it diverges, and in
> full in `hardware/esp32s3_master/README.md`.

## 1. Stack Overview & Library Analysis
- Microcontroller Hardware: ESP32 DevKit V1 class board (sensor node), selected via board = esp32dev in PlatformIO, plus an ESP32-S3 board (master node) running an Arduino IDE sketch.
- Core Framework: PlatformIO build system with Arduino C++ framework on Espressif32 for the sensor node; Arduino IDE with the same Espressif "esp32" board package for the master node (required by its TensorFlowLite_ESP32 library dependency -- see hardware/esp32s3_master/README.md's "Why Arduino IDE, not PlatformIO").

### Build and Runtime Context
- MCU family: ESP32 (dual-core Xtensa, integrated Wi-Fi, hardware PWM via LEDC, ADC1/ADC2 blocks).
- Firmware environment: [env:esp32dev] in hardware/esp32/platformio.ini.
- Monitor/upload settings:
  - monitor_speed = 115200 (matches Serial.begin(115200)).
  - upload_speed = 921600.
- Build diagnostics:
  - CORE_DEBUG_LEVEL=3 (INFO level logs in ESP core).

### Dependency Breakdown from platformio.ini
1. adafruit/DHT sensor library @ ^1.4.6
- Which library is used:
  - DHT sensor driver used through DHT.h and DHT class object.
- Why it was chosen over alternatives:
  - Mature timing-critical implementation for DHT11 one-wire style protocol.
  - Stable API, broad adoption, and good interoperability with Arduino ecosystem.
  - Lower integration risk versus writing custom bit-banged timing logic (which is error-prone under RTOS scheduling).
- How it operates inside the code:
  - Constructed once as static DHT dht(PIN_DHT_DATA, DHT11).
  - Initialized by dht.begin() in setup().
  - dht.readHumidity() and dht.readTemperature() called per sample tick in sampleDht().
  - NAN return values are treated as invalid data and the tick is skipped.

2. adafruit/Adafruit Unified Sensor @ ^1.1.14
- Which library is used:
  - Shared abstraction layer dependency required by Adafruit DHT stack.
- Why it was chosen over alternatives:
  - Official dependency path for Adafruit sensor drivers; avoids mismatch issues.
- How it operates inside the code:
  - Indirect use through DHT library internals; not directly referenced in source.

3. ESP-NOW (`esp_now.h`, bundled with the esp32 Arduino core -- no lib_deps entry)
- Which library is used:
  - Espressif's connectionless peer-to-peer WiFi-radio protocol, used in place of the JSON/HTTP request-response pattern the single-board design used.
- Why it was chosen over alternatives:
  - The sensor node no longer needs a full IP/HTTP stack to reach the master -- ESP-NOW is a raw, low-latency link over the same 2.4 GHz radio, well suited to a compact fixed-size struct sent every 5 s.
  - No AP round-trip per message; delivery is acknowledged at the radio layer via a send-status callback (`onDataSent`), which is enough for this system's hold-last-state fault model.
- How it operates inside the code:
  - `esp_now_init()`, `esp_now_register_send_cb`/`esp_now_register_recv_cb`, and `esp_now_add_peer()` with the master's MAC address (`MASTER_MAC_ADDR` in config.h) in `initEspNow()`.
  - `esp_now_send()` transmits a `SensorPacket` struct (not JSON -- a fixed-layout binary struct, memcpy'd directly into/out of the ESP-NOW payload on both boards).
  - `onDataRecv()` receives an `ActuatorCommand` struct relayed back from the master, under a critical section since the callback runs in the WiFi task context.
- Note: the master node (`hardware/esp32s3_master/`) still uses `bblanchon/ArduinoJson` and `HTTPClient.h` exactly as described in the original single-board design below -- it has simply moved from this board to that one. See `hardware/esp32s3_master/README.md`.

### Dependency Breakdown from include directives in main.cpp
1. Arduino.h
- Which library is used:
  - Arduino core API for ESP32 (timing, serial, GPIO, PWM wrapper functions).
- Why chosen:
  - Required base runtime for framework=arduino.
- How it operates inside the code:
  - Provides setup(), loop(), millis(), delay(), analogRead(), ledcSetup(), ledcWrite(), String, Serial.

2. WiFi.h / esp_wifi.h
- Which library is used:
  - ESP32 Wi-Fi radio wrapper (Arduino core) plus the lower-level esp_wifi_set_channel() from the IDF.
- Why chosen:
  - This board never associates with any access point -- no credentials, no IP, no HTTP, no NTP. WiFi.h is retained purely to bring the radio hardware up (WiFi.mode(WIFI_STA)) and read its own MAC address; esp_wifi_set_channel() then pins that radio to a fixed channel (ESPNOW_WIFI_CHANNEL, config.h) so ESP-NOW can reach the ESP32-S3 master without ever joining its AP. See config.h's "Radio" section for why the channel has to be fixed at compile time instead of negotiated by joining an AP (as this board used to do, and as the master still does for its own WiFi/HTTP leg to Django).
- How it operates inside the code:
  - WiFi.mode(WIFI_STA), WiFi.setSleep(false), WiFi.disconnect() (defensive, prevents any auto-join attempt), esp_wifi_set_channel(ESPNOW_WIFI_CHANNEL, WIFI_SECOND_CHAN_NONE), WiFi.macAddress().

3. esp_now.h
- Which library is used:
  - ESP32 ESP-NOW peer-to-peer protocol, bundled with the esp32 Arduino core.
- Why chosen:
  - Replaces HTTPClient.h/ArduinoJson.h on this board (see the ESP-NOW dependency entry above) now that Django ingestion happens on the master node instead.
- How it operates inside the code:
  - esp_now_init(), esp_now_register_send_cb/esp_now_register_recv_cb, esp_now_add_peer(), esp_now_send().

4. DHT.h
- Used to read DHT11 sensor values via DHT class.

5. math.h
- Which library is used:
  - Standard math functions.
- Why chosen:
  - Required for powf used in MQ-137 transfer function conversion.
- How it operates inside the code:
  - ppm = MQ137_A * powf(ratio, MQ137_B).

6. config.h (custom project header)
- Which header is used:
  - Firmware compile-time constants for networking, timing, pins, PWM, ADC calibration, MQ curve constants.
- Why chosen:
  - Separation of policy/constants from logic enables easier viva discussion, portability, and safer maintenance.
- How it operates inside the code:
  - Supplies all literal values referenced in setup/loop and helper functions.

### Custom C++ Source/Header Inventory
- Sensor node (PlatformIO, ESP32 DevKit V1):
  - Source: hardware/esp32/src/main.cpp
  - Header: hardware/esp32/include/config.h
- Master node (Arduino IDE sketch, ESP32-S3):
  - Sketch: hardware/esp32s3_master/esp32s3_master.ino
  - Headers: hardware/esp32s3_master/config_master.h (network/pairing config),
    hardware/esp32s3_master/model_data.h and hardware/esp32s3_master/scaler_params.h (trained
    TFLite Micro model + feature normalization -- generated artifacts, not
    hand-written logic).

## 2. Complete GPIO & Circuit Pinout Table

| Component Name | Pin / GPIO # | Component Type (Sensor/Actuator/Power) | Signal Type (Analog / Digital / I2C / SPI) | Active State (HIGH/LOW) | Technical Purpose |
| :--- | :--- | :--- | :--- | :--- | :--- |
| DHT11 Data Line | GPIO4 (PIN_DHT_DATA) | Sensor | Digital single-wire style data | Idle HIGH via pull-up, data pulses active low/high timing encoded | Reads ambient temperature and humidity in sampleDht(). |
| MQ-137 Analog Output | GPIO34 (PIN_MQ_DATA, ADC1_CH6) | Sensor | Analog (ADC1, 12-bit, 11 dB attenuation) | N/A (continuous analog voltage) | Reads NH3 proxy voltage, oversampled then converted to PPM in mqCountsToPpm(). |
| Fan PWM (speed) | GPIO32 (PIN_PWM_FAN) | Actuator | Digital PWM (LEDC channel 0, 25 kHz, 8-bit) | Duty is a *speed target*, not a power switch | Wired directly to pin 4 of a standard 4-pin PC fan (its own internal driver IC). **Not a MOSFET gate** -- the fan's +12V/GND leads are wired straight to the rail, always powered; this line only tells the fan's onboard controller what speed to target. Many such fans don't honor 0% duty as a true stop (idle at a minimum RPM floor instead) -- see PIN_FAN_ENABLE below for the actual hard-off. |
| Fan hard cutoff | GPIO27 (PIN_FAN_ENABLE) | Actuator | Digital output | HIGH = fan powered, LOW = fan de-energized | Gates an external N-MOSFET on the fan's GND leg for a genuine power cutoff, independent of the PWM line's speed-target semantics above. Driven alongside `PWM_FAN_CHANNEL` in `applyActuators()`: HIGH whenever `fan_pwm > 0`, LOW otherwise. |
| Heater Relay | GPIO25 (PIN_HEATER_RELAY) | Actuator | Digital output | Active-LOW: LOW = heater ON, HIGH = heater OFF | Switches the PTC heater's relay whenever the master-relayed `heater_pwm` byte is nonzero (master computes it from LOW_TEMP_ALERT classification, or a dashboard MANUAL override); ON/OFF only, no speed target -- unlike the fan, this is a plain relay module, not a PWM-driven MOSFET gate. |
| USB-UART Serial (console) | UART0 default pins (board routed via USB bridge) | Debug/Interface | Digital UART | TX active-high line logic | Boot logs, diagnostics, telemetry printouts at 115200 baud. |

### Electrical and Pin-Selection Rationale
- GPIO34 is input-only and mapped to ADC1, which remains usable while Wi-Fi is active; this is critical because ADC2 is unavailable during active Wi-Fi on classic ESP32. This still holds with ESP-NOW: the radio stays powered on a fixed channel for ESP-NOW the whole time (see below), even though this board never actually associates with an access point -- the same ADC1-vs-radio-active constraint applies either way.
- Fan PWM (GPIO32) and its hard-cutoff MOSFET gate (GPIO27) are both general-purpose, non-strapping pins with nothing else assigned to them. The heater relay (GPIO25) is likewise general-purpose/non-strapping; unlike the fan, it's a plain ON/OFF relay module, not a PWM/LEDC channel.
- DHT11 data line on GPIO4 is a common safe GPIO with external 10 kOhm pull-up assumption.

## 3. Communication & Data Transmission Pipeline

Two hops now, not one:

```
Sensor node (ESP32)  --ESP-NOW-->  Master node (ESP32-S3)  --WiFi/HTTP-->  Django
       ^                                                          |
       `------------------ ESP-NOW (classification) --------------'
```

- Hop 1 -- sensor node to master, ESP-NOW:
  - Physical/link: IEEE 802.11 Wi-Fi radio, used in ESP-NOW connectionless mode (no association/handshake, no IP). The sensor node never joins any access point at all -- it has no WiFi credentials, gets no IP, and speaks nothing but ESP-NOW; only the ESP32-S3 master joins the AP (for its own WiFi/HTTP leg to Django).
  - Transport/application: a fixed-layout `SensorPacket` C struct, sent with `esp_now_send()` directly to the master's MAC address -- no serialization, no HTTP.
  - Both radios must still share a WiFi channel for ESP-NOW to work even without either side "connecting" in the usual sense -- previously guaranteed by having both boards join the same AP and inherit its channel; now the sensor node fixes its channel at compile time instead (`ESPNOW_WIFI_CHANNEL`, `esp32/include/config.h`), since it no longer has an AP to negotiate one from. The master still gets its channel from the router as before and logs a boot-time warning if the two ever disagree (see `esp32s3_master/include/config.h`'s `ESPNOW_WIFI_CHANNEL`).
- Hop 2 -- master to Django, WiFi/HTTP (this is the leg the rest of this document originally described end-to-end; it is unchanged in mechanism, only relocated to the ESP32-S3 board):
  - Physical/link: IEEE 802.11 Wi-Fi in station mode.
  - Transport: TCP/IP.
  - Application: HTTP REST POST with JSON payload.
  - Endpoint: `POST http://{discovered-django-host}:8000/api/telemetry/submit/` -- the host IP is no longer hardcoded; the master finds it via a UDP broadcast discovery handshake at boot (see `hardware/esp32s3_master/README.md` "Discovery" section and `telemetry/discovery.py`).
- Return path -- Django's classification travels master -> sensor node over ESP-NOW as an `ActuatorCommand` struct, the mirror image of hop 1.

### Sensor Node Request Flow (per 5 s tick)
1. initRadio() runs once at boot (WiFi.mode(WIFI_STA) + esp_wifi_set_channel()) -- no per-loop WiFi maintenance call exists anymore, since there's no AP association to lose or reconnect.
2. Any pending ActuatorCommand relayed from the master since the last iteration is applied via applyActuators() -- checked every loop iteration, independent of the sampling cadence.
3. Sampling tick gate uses millis() against nextSampleAt; executes every SAMPLE_INTERVAL_MS (5000 ms).
4. sampleDht() obtains humidity and temperature; invalid NAN data aborts current tick.
5. sampleMq137() gathers 16 ADC samples on GPIO34 and averages.
6. sendSample() populates a SensorPacket (temperature/humidity/ammonia_ppm only -- no hour/month; the master supplies hour itself from its own NTP sync, see the Master Node Flow below) and calls esp_now_send() to the master's MAC address.
7. onDataSent() (registered callback) logs delivery failure asynchronously; no application-level retry -- the next 5 s tick supersedes a lost sample.

### Master Node Flow (per received packet)
1. onDataRecv() copies the incoming SensorPacket out of the ESP-NOW payload under a critical section (runs in the WiFi task context).
2. loop() folds the fresh sample into a rolling 10-minute accumulation bucket. Once that bucket finalizes, its lag/rolling/delta features are computed against a 7-bucket history (model_runner.cpp) and fed into the TFLite Micro model as a flat 44-feature vector -- **not** a small raw-sample window; the retrained model needs 7 finalized 10-minute buckets (lag6 = 60 min back + the current bucket) before its first inference, i.e. **~70 minutes after boot**, not the ~45 s the earlier windowed model needed. See hardware/esp32s3_master/README.md's "Model architecture" section for the full feature list and why the wait is what it is (the model was trained on 10-minute-resampled data, not the sensor's real 5s cadence).
3. Once warmed up, the interpreter runs one inference per finalized bucket, producing predicted_temperature and predicted_ammonia (~10 minutes ahead -- this "10 minutes" is the forecast's time horizon, unrelated to the ~70-minute warm-up wait above) plus two spike probabilities (predicted_spike_probability for ammonia, and a temperature-spike probability not yet surfaced to Django/the dashboard).
4. postToDjango() builds the combined JSON record (raw + predictions, null while still warming up) and POSTs it -- same StaticJsonDocument/HTTPClient pattern the single-board design used.
5. On HTTP 201, the response's record.predicted_class is parsed and relayed back to the sensor node via esp_now_send().
6. On any failure (WiFi down, non-201, parse error), nothing is relayed -- the sensor node's actuators simply hold their last commanded state, the same fail-safe behavior the original single-board design had.

### Payload Inspection

ESP-NOW SensorPacket (sensor node -> master, binary struct, not JSON):
- seq (uint32_t)
- temperature (float)
- humidity (float)
- ammonia_ppm (float)

No hour/month fields -- the sensor node has no WiFi/NTP of its own (see
"Hop 1" above), so it can't supply either. The master now reads its own
NTP-synced clock (currentHour() in main.cpp) to source the hour-of-day
cyclic feature the on-device model needs; month was already unused by the
retrained model before this change.

ESP-NOW ActuatorCommand (master -> sensor node, binary struct):
- state (char[24], one of the four EnvironmentalState values)

Outgoing JSON fields from the master's postToDjango() (unchanged contract from the original single-board transmit(), plus one new field):
- temperature (float)
- humidity (float)
- ammonia_level (float)
- predicted_temperature (float or null)
- predicted_ammonia (float or null)
- predicted_spike_probability (float in [0, 1] or null) -- new: the TFLite Micro classifier head's ammonia-spike probability, absent/null until the master node is linked.

Example payload (master node, prediction populated):
{
  "temperature": 30.25,
  "humidity": 62.10,
  "ammonia_level": 11.40,
  "predicted_temperature": 30.90,
  "predicted_ammonia": 12.00,
  "predicted_spike_probability": 0.14
}

Example payload (master node, before its ~70-minute bucket-history warm-up completes -- see hardware/esp32s3_master/README.md's "Model architecture" section):
{
  "temperature": 30.25,
  "humidity": 62.10,
  "ammonia_level": 11.40,
  "predicted_temperature": null,
  "predicted_ammonia": null,
  "predicted_spike_probability": null
}

### Server Response Parsing (Backend -> Master Node)
- Expected status code: 201 Created only.
- Expected response envelope from Django:
  - status: "ok"
  - record: object containing persisted telemetry, including predicted_class.
- Parsed key path in firmware:
  - respDoc["record"]["predicted_class"]
- Valid states expected by firmware switch logic:
  - CRITICAL_AMMONIA
  - HEAT_STRESS_WARNING
  - LOW_TEMP_ALERT
  - OPTIMAL_ENVIRONMENT
- This classification is then re-sent to the sensor node as an ActuatorCommand over ESP-NOW -- the master never applies fan/heater state itself, it only relays.

### Fault Tolerance and Error Behavior
- Wi-Fi disconnection handling (both boards):
  - ensureWifi() checks WiFi.status().
  - If disconnected: WiFi.disconnect(true, true) then connectWifi().
  - connectWifi() retries up to WIFI_MAX_RETRIES (10) with WIFI_RETRY_MS (2000 ms).
- ESP-NOW delivery handling (both hops):
  - Send status is checked asynchronously via the registered send callback; a failure is logged, not retried -- the next 5 s tick supersedes a lost sample or a lost classification.
  - No acknowledgment-based retry loop exists in either direction; this is a deliberate simplicity trade-off appropriate for a 5 s telemetry cadence where a single dropped packet is inconsequential.
- Timeout handling (master node only, HTTP leg):
  - HTTP timeout set to HTTP_TIMEOUT_MS (4000 ms), bounding stall duration inside postToDjango().
- HTTP error handling (master node only):
  - Any status != 201 is treated as failure and logged; no classification is relayed back for that sample.
  - No in-function retry; retry naturally occurs on next received ESP-NOW sample.
- JSON parse failure handling (master node only):
  - deserializeJson error returns failure; ESP-NOW relay to the sensor node is skipped.
- Packet loss/outage behavior:
  - Any break in the chain (ESP-NOW sensor->master, master's WiFi/HTTP, or ESP-NOW master->sensor) results in no new actuator command reaching the sensor node.
  - Actuators remain at previous duty values (held state), because applyActuators() only runs when a fresh ActuatorCommand arrives. This is unchanged from the original single-board design, just spread across an additional hop -- more links in the chain means more places a single sample can be lost, though the failure mode at the actuator is identical.
- Sensor fault handling (sensor node):
  - DHT NAN -> skip tick.
  - MQ rail/open-circuit voltage guard returns 0.0 ppm instead of inf/NaN propagation.
  - NH3 output clamped to [0, 500] ppm to align backend admissible range.
- Clock fault handling (sensor node):
  - NTP sync failure at boot is logged but non-fatal; currentHourMonth() falls back to the last successfully-read hour/month (seeded to a neutral noon/June default on cold start) so a clock outage degrades forecast accuracy rather than stalling sampling.

## 4. Execution Flow & Logic Breakdown

### Setup Initialization (setup())
1. Serial monitor configuration and baud:
  - Serial.begin(115200), then short delay(50), then boot log print.
2. Pin/peripheral initialization:
  - dht.begin() initializes DHT11 stack.
  - analogReadResolution(12) sets ADC to 12-bit.
  - analogSetAttenuation(ADC_11db) configures approximately 0..3.3V range.
3. Actuator setup:
  - Fan: ledcSetup()/ledcAttachPin() configure and attach the LEDC PWM
    channel on PIN_PWM_FAN, then ledcWrite() to PWM_DUTY_OFF; PIN_FAN_ENABLE
    is set as a digital output and driven LOW (de-energized) immediately, so
    the fan doesn't glitch on before its first control cycle.
  - Heater: pinMode(OUTPUT) + digitalWrite for PIN_HEATER_RELAY, driven to
    HEATER_RELAY_OFF (HIGH, active-LOW module) immediately, same
    don't-glitch-on-boot precaution.
4. Wi-Fi connection loop and handling:
  - connectWifi() enters STA mode, disables modem sleep, begins association, retries with bounded loop.
5. NTP time sync:
  - syncNtpTime() calls configTime() then attempts one getLocalTime() read (bounded by NTP_SYNC_TIMEOUT_MS) purely for a diagnostic boot-time log line; a failure here is not fatal, see currentHourMonth()'s fallback.
6. ESP-NOW bring-up:
  - initEspNow() registers send/recv callbacks and adds the master node (MASTER_MAC_ADDR) as a peer; setup() halts in an infinite delay loop if this fails, since nothing downstream can function without it.
7. Sensor warmup/stabilization:
  - No explicit timed warmup state machine; first sample can run immediately after setup via nextSampleAt = millis().
  - Practical note: MQ-137 typically needs burn-in and runtime thermal stabilization externally managed.

### Main Loop Mechanics (loop())
1. Non-blocking timing strategy:
  - Uses millis() schedule check:
    - if (int32_t(now - nextSampleAt) < 0) return.
  - This signed-delta pattern is rollover-safe across millis() wrap (~49.7 days).
2. Connectivity maintenance:
  - ensureWifi() runs every iteration, not gated by the sample timer.
3. Actuator relay check (also ungated by the sample timer):
  - If g_newCommand is set (populated by the onDataRecv ESP-NOW callback), copy it out under a critical section and call applyActuators().
4. Schedule advancement:
  - nextSampleAt = now + SAMPLE_INTERVAL_MS.
5. Sensor sequence:
  - Read DHT11 via sampleDht(); abort tick on failure.
  - Read MQ via sampleMq137() with oversampling and conversion.
6. Transmission sequence:
  - sendSample() populates a SensorPacket (including currentHourMonth()'s wall-clock fields) and calls esp_now_send() to the master.
7. Failure branch behavior:
  - Logs a failure message on a local send error; actuators are unaffected by this board's own send failures (they only change in response to an incoming ActuatorCommand, or lack thereof).

Forecasting and classification no longer happen on this board at all -- see the Master Node Flow above and hardware/esp32s3_master/README.md for where that logic now lives.

## 5. Exhaustive Function & Logic Index

### 5.1 static void connectWifi()
- Function Signature: static void connectWifi()
- Exact Job:
  - Bring Wi-Fi STA link up with bounded retry and diagnostics.
- Step-by-Step Logic:
1. Configure Wi-Fi mode to station.
2. Disable Wi-Fi sleep for lower control-loop latency.
3. Start association using SSID/password constants.
4. Print association attempt log.
5. Loop up to WIFI_MAX_RETRIES:
  - Check WiFi.status() for WL_CONNECTED.
  - On success, print IP and RSSI, then return.
  - Otherwise delay(WIFI_RETRY_MS) and print retry count.
6. If loop exits without success, print failure message and return.

### 5.2 static void ensureWifi()
- Function Signature: static void ensureWifi()
- Exact Job:
  - Maintain link continuity during runtime by reconnecting when disconnected.
- Step-by-Step Logic:
1. If currently connected, immediate return.
2. Print link-lost log.
3. Force disconnect and erase existing state (disconnect(true, true)).
4. Call connectWifi() to re-associate.

### 5.3 static bool sampleDht(float& temperatureC, float& humidityPct)
- Function Signature: static bool sampleDht(float& temperatureC, float& humidityPct)
- Exact Job:
  - Acquire valid DHT11 humidity and temperature reading pair.
- Step-by-Step Logic:
1. Read humidity.
2. Read temperature in Celsius.
3. Check either value for NAN.
4. If NAN present, print diagnostic and return false.
5. Otherwise return true with reference outputs populated.

### 5.4 static float mqCountsToPpm(uint32_t sumCounts, uint16_t samples)
- Function Signature: static float mqCountsToPpm(uint32_t sumCounts, uint16_t samples)
- Exact Job:
  - Convert averaged ADC counts from MQ-137 output into bounded NH3 PPM estimate.
- Step-by-Step Logic:
1. Compute avgCounts = sumCounts / samples.
2. Convert counts to voltage vOut using ADC_MAX_COUNTS and ADC_MAX_VOLTS.
3. Rail/open-circuit guard:
  - If vOut < 0.05V or vOut > (MQ137_VC_VOLTS - 0.05V), return 0.0.
4. Compute sensor resistance:
  - rs = RL * (Vc - vOut) / vOut.
5. Compute ratio = rs / R0.
6. Convert via power-law fit:
  - ppm = MQ137_A * powf(ratio, MQ137_B).
7. Clamp negative to 0.0.
8. Clamp above 500.0 to 500.0.
9. Return ppm.

### 5.5 static float sampleMq137()
- Function Signature: static float sampleMq137()
- Exact Job:
  - Perform oversampled analog acquisition then convert to NH3 PPM.
- Step-by-Step Logic:
1. Initialize 32-bit sum accumulator.
2. For i in 0..MQ_ADC_SAMPLES-1:
  - Read analog value from PIN_MQ_DATA.
  - Add to sum.
  - delayMicroseconds(200) for ADC settling.
3. Call mqCountsToPpm(sum, MQ_ADC_SAMPLES).
4. Return computed ppm.

### 5.6 static void syncNtpTime() / static void currentHourMonth(uint8_t&, uint8_t&)
- Function Signature: static void syncNtpTime(); static void currentHourMonth(uint8_t& hour, uint8_t& month)
- Exact Job:
  - Source wall-clock hour-of-day/month-of-year for the master's model features, without letting a clock fault stall sensor sampling.
- Step-by-Step Logic:
1. syncNtpTime() calls configTime(GMT_OFFSET_SEC, DAYLIGHT_OFFSET_SEC, NTP_SERVER), then getLocalTime() once with a bounded timeout purely to log success/failure at boot.
2. currentHourMonth() calls getLocalTime() with a zero timeout (non-blocking check) on every sample tick.
3. On success, updates and returns the static lastHour/lastMonth (seeded to 12/6 on cold start).
4. On failure, silently returns the last-known values -- no error path, since a stale clock reading is preferable to skipping a sample.

### 5.7 static bool sendSample(float temperatureC, float humidityPct, float ammoniaPpm)
- Function Signature: static bool sendSample(float temperatureC, float humidityPct, float ammoniaPpm)
- Exact Job:
  - Marshal a SensorPacket and hand it to the ESP-NOW stack for delivery to the master. Replaces the original transmit()'s JSON-over-HTTP responsibility with a binary-struct-over-ESP-NOW one; there is no response to parse here, since the classification comes back later, asynchronously, via onDataRecv().
- Step-by-Step Logic:
1. Populate a SensorPacket: incrementing seq, the three live readings, and hour/month from currentHourMonth().
2. Call esp_now_send(masterMac, ...) with the packet's raw bytes.
3. Return true iff esp_now_send() itself queued successfully (ESP_OK) -- this reports local queuing, not remote delivery; actual delivery success/failure surfaces later via the onDataSent callback.

### 5.8 static void onDataSent(...) / static void onDataRecv(...)
- Function Signature: static void onDataSent(const uint8_t* mac, esp_now_send_status_t status); static void onDataRecv(const esp_now_recv_info_t* info, const uint8_t* data, int len)
- Exact Job:
  - Asynchronous ESP-NOW callbacks, invoked from the WiFi task context (not the Arduino loop() thread).
- Step-by-Step Logic:
1. onDataSent(): logs a delivery-failure diagnostic if status != ESP_NOW_SEND_SUCCESS; no other action.
2. onDataRecv(): validates the incoming length matches sizeof(ActuatorCommand); if so, memcpy's the payload into g_lastCommand and sets g_newCommand under a critical section (portENTER_CRITICAL_ISR/portEXIT_CRITICAL_ISR) so loop() can safely consume it without a torn read.

### 5.9 static void applyActuators(uint8_t fan_pwm, uint8_t heater_pwm)
- Function Signature: static void applyActuators(uint8_t fan_pwm, uint8_t heater_pwm)
- Exact Job:
  - Apply two bytes the master has already fully computed -- this board makes
    no actuation decisions of its own any more (no `state`/classification
    parameter at all). fan_pwm is real PWM (0-255 duty, from the master's
    MLP-predicted NH3 error or a dashboard MANUAL override); heater_pwm is a
    0-255 byte (from the classification -- LOW_TEMP_ALERT -> 255, else 0 --
    or a dashboard MANUAL override) that this board only thresholds, since
    its heater is a plain active-LOW relay with no speed target.
- Step-by-Step Logic:
1. heaterOn = (heater_pwm > 0).
2. digitalWrite(PIN_HEATER_RELAY, heaterOn ? HEATER_RELAY_ON : HEATER_RELAY_OFF)
   -- HEATER_RELAY_ON is LOW (active-LOW relay module), HEATER_RELAY_OFF is HIGH.
3. digitalWrite(PIN_FAN_ENABLE, fan_pwm > 0 ? HIGH : LOW) -- hard power
   cutoff, independent of the PWM duty's own speed-target semantics (see
   GPIO27 row in the pinout table).
4. ledcWrite(PWM_FAN_CHANNEL, fan_pwm) -- write the speed target to the
   fan's PWM line.
- **Not interlocked:** fan and heater CAN be ON simultaneously -- fan_pwm and
  heater_pwm are computed independently on the master (and either can come
  from a MANUAL dashboard override, decoupled from the other), so e.g. a
  nonzero MANUAL fan override alongside a nonzero heater_pwm runs the fan and
  energizes the heater relay at once. Earlier revisions of this function
  guaranteed mutual exclusion (a single classification string drove both
  outputs, decided locally on this board); that guarantee no longer holds
  and is not currently re-enforced anywhere in either firmware.

### 5.10 void setup()
- Function Signature: void setup()
- Exact Job:
  - One-time initialization of serial, sensors, ADC, PWM, Wi-Fi, NTP, ESP-NOW, and scheduler seed.
- Step-by-Step Logic:
1. Start serial at 115200.
2. Print boot banner.
3. Initialize DHT sensor.
4. Configure ADC resolution and attenuation.
5. Configure and attach the fan's LEDC PWM channel/pin (PWM_FAN_CHANNEL on
   PIN_PWM_FAN); configure PIN_FAN_ENABLE and PIN_HEATER_RELAY as plain
   digital outputs.
6. Force both actuators OFF before anything else runs: fan PWM duty 0 +
   PIN_FAN_ENABLE LOW; heater relay HEATER_RELAY_OFF (HIGH, active-LOW
   module).
7. Establish Wi-Fi connection (connectWifi()).
8. Sync NTP time (syncNtpTime()).
9. Bring up ESP-NOW and register the master as a peer (initEspNow()); halt in an infinite delay loop on failure.
10. Seed nextSampleAt with current millis for immediate first cycle.

### 5.11 void loop()
- Function Signature: void loop()
- Exact Job:
  - Real-time cooperative control loop: maintain connectivity, apply any relayed actuator command, sample sensors, and transmit telemetry over ESP-NOW.
- Step-by-Step Logic:
1. ensureWifi() to maintain link.
2. Apply any pending ActuatorCommand from the master (checked every iteration, not gated by the sample timer).
3. Read now = millis().
4. If not yet sample time (signed delta negative), return quickly.
4. Schedule next sample time by adding SAMPLE_INTERVAL_MS.
5. Read DHT values; if invalid, abort tick.
6. Read ammonia ppm via sampleMq137().
7. Compute forecast values and validity flag.
8. Call sendSample() over ESP-NOW with the live readings (this board no
   longer computes a forecast itself -- see item 2 above for where
   applyActuators(fan_pwm, heater_pwm) actually runs, gated on a fresh
   ActuatorCommand rather than on this step).
9. If the send succeeded, print the formatted `[TX]` telemetry line.
10. Else, print the failure line and retain current actuator state (held
    from the last applyActuators() call).

## 6. Evaluator Defense Guide: 10 Tough Questions Teachers Will Ask

1. Network: How does data get from the sensor to Django, and why ESP-NOW for one hop and HTTP POST for the other?
- Answer:
  - Two different jobs, two different protocols. Sensor node -> master node needs to move a small fixed-size struct between two boards a few meters apart, every 5 s, with minimal latency and no need for either board to run a full IP stack against each other -- ESP-NOW (a connectionless link directly over the WiFi radio) fits that exactly, and is simpler and lower-latency than standing up a second HTTP server on the master just to receive from the sensor node. Master node -> Django is a different job: crossing onto the LAN/internet to reach a server that already speaks HTTP, where POST is correct semantically because each payload creates a new telemetry record server-side (non-idempotent create), while GET risks caching/proxy behavior. WebSockets would suit a continuous duplex stream but add connection-lifecycle complexity neither side needs for one compact sample every 5 s.

2. Concurrency: Why is non-blocking millis timing used instead of delay(), and what happens if millis overflows after 49 days?
- Answer:
  - The control loop uses cooperative scheduling so connectivity checks and future compute tasks can run each loop iteration. The check uses signed subtraction: int32_t(now - nextSampleAt) < 0. That delta arithmetic is rollover-safe, so when millis wraps, relative ordering remains valid and scheduling continues correctly.

3. Circuitry: How do your digital outputs physically trigger relays to switch high-voltage fans and heaters?
- Answer:
  - Both the fan (GPIO32) and heater (GPIO25) now use the same actuation strategy: a plain digital ON/OFF output into a relay module's IN pin, not a bare relay coil and not a PWM/MOSFET-gate speed control. Relay modules integrate their own driver transistor and flyback diode on-board, so a direct GPIO connection is the module's intended interface -- no external MOSFET/transistor stage is needed on this board's side for either actuator. High-voltage isolation and flyback protection for both loads' inductive switching are handled inside the respective relay modules themselves.

4. Data Parsing: Which library parses the incoming server JSON, and how do you prevent buffer overflow attacks or low memory issues on the MCU?
- Answer:
  - This now happens on the master node (ESP32-S3), not the sensor node: ArduinoJson is used there with fixed-capacity StaticJsonDocument (320 bytes outgoing, 384 bytes incoming), preventing uncontrolled heap growth and reducing fragmentation risk. Parse errors are explicitly checked via DeserializationError. Only one expected field path is extracted for control action, limiting attack surface from oversized or malformed payloads. The sensor node itself parses no JSON at all any more -- its two payloads (SensorPacket out, ActuatorCommand in) are fixed-size C structs copied with memcpy and a length check, which removes JSON parsing from that board's attack surface entirely.

5. Reliability: What happens to the physical heaters/fans if the Wi-Fi drops, the Python backend crashes, or a board goes offline?
- Answer:
  - The chain has three links now (sensor-to-master ESP-NOW, master-to-Django HTTP, master-to-sensor ESP-NOW), and a break at any one of them has the same net effect: the sensor node's applyActuators() is not called, so previous actuator duty values are held -- deterministic hold-last-state behavior, unchanged in spirit from the original single-board design. Concretely: if the master node is powered off, the sensor node keeps sampling and sending, but esp_now_send() calls will simply fail to reach a live peer and nothing comes back; if Django is down, the master's postToDjango() returns false and no ESP-NOW relay is sent; if WiFi drops on either board, ensureWifi() retries independently on each. In production, a watchdog-safe policy can be added (for example, fail-safe fan ON after N consecutive failures) depending on farm safety requirements -- not implemented here on either board.

6. Sensors: How do you handle sensor noise, erratic analog readings, or floating inputs?
- Answer:
  - DHT errors are detected through NAN and discarded for that tick. MQ analog noise is reduced by oversampling 16 reads with microsecond settling. Rail guards identify likely wiring/open-circuit conditions and return 0.0 instead of unstable math. Final PPM is clamped to [0,500], matching backend plausibility bounds.

7. Power & Hardware: What are the voltage levels (3.3V vs 5V) for your sensors and relays, and did you need logic level shifters?
- Answer:
  - ESP32 GPIO/ADC are 3.3V domain. GPIO34 ADC input must never exceed 3.3V; config comments explicitly require external scaling if MQ module output can approach 5V. MQ sensor supply Vc in model is 5.0V, but ADC pin sees conditioned voltage. Relay power stages for fan/heater are external modules and should include proper level compatibility and isolation as required by the chosen relay hardware.

8. Memory: How is RAM/Flash usage managed on these microcontrollers?
- Answer:
  - Sensor node: static/global objects throughout (no JSON documents at all now), fixed-size SensorPacket/ActuatorCommand structs, no dynamic allocation in the loop. Master node: the same StaticJsonDocument discipline the original design used for its HTTP leg, plus a large but fixed 220 KB tensor arena (kTensorArenaSize) for the TFLite Micro interpreter -- sized once at compile time, never grown at runtime, which is why the ESP32-S3 (more RAM than the classic ESP32) was chosen for this role rather than adding the model to the existing DevKit V1.

9. Payload Construction: How are continuous float/integer sensor values converted for transmission?
- Answer:
  - Sensor node -> master: no conversion at all -- a SensorPacket C struct is sent as raw bytes over ESP-NOW (memcpy on both ends), which is both simpler and smaller on the wire than JSON for a fixed, known schema. Master -> Django: values remain numeric in the JSON tree (doc[field] = float) and are serialized by ArduinoJson via serializeJson into a String body, exactly as the original single-board design did. No manual sprintf JSON framing is used on that leg, reducing formatting errors and type coercion issues; Django's decoder reads numeric JSON tokens directly into Python float validation.

10. Security: How could this system be secured in a production environment?
- Answer:
  - Two legs, two hardening stories. ESP-NOW (both directions) supports AES-CCMP encryption via esp_now_add_peer()'s peer.encrypt/peer.lmk fields -- currently disabled (peer.encrypt = false) since this is a private/trusted LAN deployment; enabling it and provisioning a shared LMK per peer pair would be the production step. Master -> Django HTTP should be replaced with HTTPS via WiFiClientSecure, pinning the server certificate or CA chain and enforcing TLS version/cipher policy, plus device authentication (API key or mTLS client cert), replay protection (timestamp/nonce + HMAC), and network segmentation (VLAN/firewall). Both boards should also move their compile-time WiFi/MAC constants out of version-controlled headers and into secure onboarding/NVS provisioning for a real fleet deployment.

### Additional Defense Notes for Viva
- Classification precedence is intentionally ammonia-dominant:
  - Backend classifier evaluates ammonia > 15.0 first, then heat stress (temperature alone crossing the age-band ceiling -- humidity is no longer a condition -- triggered by either the live reading or the Edge-AI forecast), then low temperature. The master node's spike-risk prediction is a separate, advisory-only signal (predicted_spike_probability) and never itself changes this precedence or the resulting predicted_class; the Edge-AI temperature forecast is the one deliberate exception to "forecasts are advisory-only," since it can trigger HEAT_STRESS_WARNING on its own ahead of the live reading (see telemetry/classifier.py's docstring).
- Firmware and backend state vocabularies are byte-aligned:
  - STATE_* constants in the sensor node's firmware, and the classification strings the master node relays, must remain identical to backend EnvironmentalState values.
- ESP-NOW packet structs must stay byte-identical across both boards:
  - SensorPacket and ActuatorCommand are defined independently in hardware/esp32/src/main.cpp and hardware/esp32s3_master/esp32s3_master.ino (no shared header, since they're built by two different toolchains). Changing field order/types in one without the other silently breaks the link -- onDataRecv()'s length check (len != sizeof(...)) will reject the mismatched packets outright, which at least fails loudly rather than silently misinterpreting bytes.
- Important current limitations to disclose clearly:
  - On repeated communication failures anywhere in the three-hop chain, actuator policy is hold-last-state, not explicit fail-safe override; safety strategy should be reviewed for deployment.
  - Single sensor node, single master node only -- see hardware/esp32s3_master/README.md's "Known limitations" for what multi-node support would require.
  - MAC addresses are paired manually at flash time (copy-paste from Serial Monitor output); there is no dynamic pairing/discovery handshake.

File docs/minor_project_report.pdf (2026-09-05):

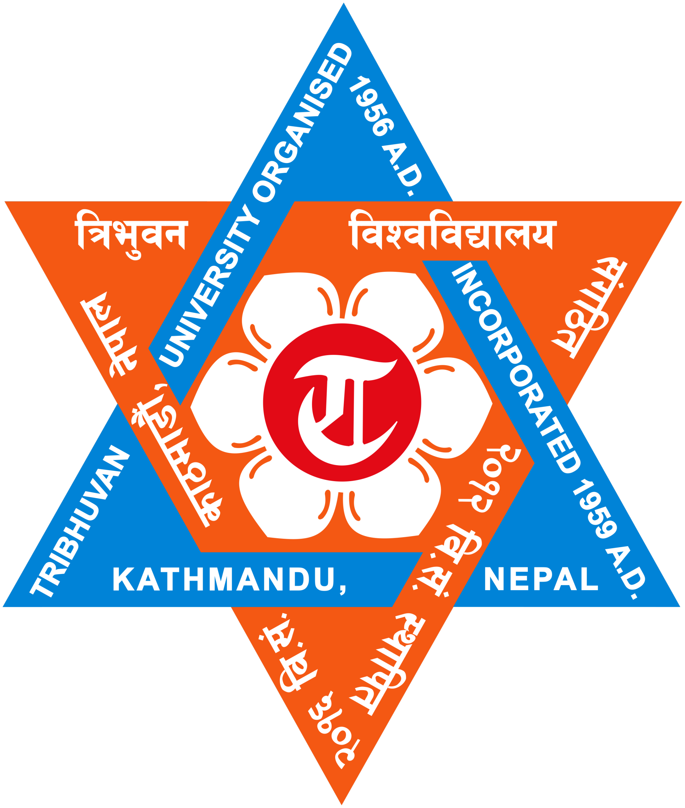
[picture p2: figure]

TRIBHUVAN UNIVERSITY

INSTITUTE OF ENGINEERING

THAPATHALI CAMPUS

A MINOR PROJECT REPORT

ON

EDGE-AI BASED PREDICTIVE CLOSED CONTROL SYSTEM FOR SMART

POULTRY FARMING

Submitted By:

Amir Bhattarai | (THA080BEI005)
Aviral Adhikari | (THA080BEI011)
Balram Sharma Kandel | (THA080BEI012)
Bikash Bk | (THA080BEI015)

Submitted To:

Department of Electronics and Computer Engineering

Thapathali Campus

Kathmandu, Nepal

August 2026

TRIBHUVAN UNIVERSITY

INSTITUTE OF ENGINEERING

THAPATHALI CAMPUS

A MINOR PROJECT REPORT

ON

EDGE-AI BASED PREDICTIVE CLOSED CONTROL SYSTEM FOR SMART

POULTRY FARMING

Submitted By:

Amir Bhattarai | (THA080BEI005)
Aviral Adhikari | (THA080BEI011)
Balram Sharma Kandel | (THA080BEI012)
Bikash Bk | (THA080BEI015)

Submitted To:

Department of Electronics and Computer Engineering

Thapathali Campus

Kathmandu, Nepal

In partial fulfillment for the award of the

Bachelors Degree in Electronics, Communication and Information Engineering

Under the Supervision of

Er. Anup Shrestha

August 2026

DECLARATION

We hereby declare that the project entitled, “EDGE-AI BASED PREDICTIVE CLOSED CONTROL SYSTEM FOR SMART POULTRY FARMING” in the partial fulfillment of the requirements for the award of the Degree of Bachelor of Engineering Electronics, Communication and Information Engineering is a bona fide report of the work carried out by us. These materials contained within the report have not been submitted to any University or Institution for the award of any degree, and we are the only author of this complete work and no sources other than the listed ones have been used in this work.

Amir Bhattarai | (THA080BEI005)
Aviral Adhikari | (THA080BEI011)
Balram Sharma Kandel | (THA080BEI012)
Bikash Bk | (THA080BEI015)

Date: August 2026

i

CERTIFICATE OF APPROVAL

The undersigned certify that they have read and recommended to the Department of Electronics and Computer Engineering, IOE, Thapathali Campus, a minor project work entitled “EDGE-AI BASED PREDICTIVE CLOSED CONTROL SYSTEM FOR SMART POULTRY FARMING” submitted by Amir Bhattarai, Aviral Adhikari, Balram Sharma Kandel, Bikash Bk in partial fulfillment for the award of Bachelor of Engineering in Electronics, Communication and Information Engineering. The project was carried out under the special supervision and within the time prescribed by the syllabus.

We found that the students to be hardworking, skilled and ready to undertake any related work to their field of study and hence we recommend the award of partial fulfillment of Bachelor’s Degree of Electronics, Communication, and Information Engineering.

Project Supervisor
Er. Anup Shrestha
Department of Electronics and Computer Engineering
Thapathali Campus, IOE

External Examiner

Project Coordinator
Er. Praches Acharya
Department of Electronics and Computer Engineering
Thapathali Campus, IOE

Head of Department
Er. Umesh Kanta Ghimire
Department of Electronics and Computer Engineering
Thapathali Campus, IOE

August 2026

ii

COPYRIGHT

The author has agreed that the library, Department of Electronics and Computer Engineering, Thapathali Campus, may make this report freely available for inspection. Moreover, the author has agreed that the permission for extensive copying of this project work for scholarly purpose may be granted by the professor/lecturer, who supervised the project work recorded herein or, in their absence, by the head of the department. It is understood that the recognition will be given to the author of this report and to the Department of Electronics and Computer Engineering, IOE, Thapathali Campus in any use of the material of this report. Copying of publication or other use of this report for financial gain without approval of the Department of Electronics and Computer Engineering, IOE, Thapathali Campus and author’s written permission is prohibited.

Request for permission to copy or to make any use of the material in this project in whole or part should be addressed to department of Electronics and Computer Engineering, IOE, Thapathali Campus.

iii

ACKNOWLEDGEMENT

We would like to thank Institute of Engineering, Tribhuvan University, for incorporating major project within the curriculum of Bachelor’s in Electronics, Communication, and Information Engineering.

Special thanks to our supervisor, Er. Anup Shrestha, for his guidance, invaluable feedback, and constant support for the project. His expertise, experience in domain knowledge of Scheduling and encouragement have been pivotal in shaping this project.

We would like to express our appreciation to the Department of Electronics and Computer Engineering, for their continuous assistance, recommendations during project selection. This has significantly helped in enabling our professional development.

We extend our sincere thanks to all the teachers, friends, and both direct and indirect contributors for their valuable insights, recommendations, and encouragement throughout this journey.

Amir Bhattarai | (THA080BEI005)
Aviral Adhikari | (THA080BEI011)
Balram Sharma Kandel | (THA080BEI012)
Bikash Bk | (THA080BEI015)

iv

ABSTRACT

Industrial poultry farming relies on raising chickens in an artificial controlled environment that must provide all the conditions. Critical environmental factors like temperature and ammonia must remain within safe limits as unfavourable conditions can negatively affect bird growth so these factors should be well monitored and controlled. Traditional monitoring systems are reactive and would alert the administrator only after the threshold for the danger level exceeds. This project presents a distributed Edge-AI architecture that makes the poultry management autonomous and includes predictive intervention for the problems occurring in poultry farms. The hardware architecture consists of a network of ESP32 microcontrollers which communicate between themselves using ESP-NOW. One node interfaces with sensors for continuous monitoring of ammonia and temperature levels, while the other node runs a TinyML model trained on PC and deployed remotely using TensorFlow Lite library that predicts the environmental spikes before they occur, forming a closed-loop control system that triggers ventilation or turns on the heating element to mitigate the possible dangers of uncontrolled ammonia and temperature level. Furthermore, all predictive data and system analytics are aggregated via Wi-Fi to a centralized web dashboard and alert messages in case of critical conditions, providing farm administrators with a scalable, real-time dashboard for proactive agricultural management.

Keywords — Ammonia Monitoring, Broiler, DHT22, Edge-AI, Environmental Control, ESP32, IoT, MQ-137, Real-Time Monitoring, TinyML, Ventilation Control

v

TABLE OF CONTENTS

vi

vii

LIST OF FIGURES

Figure 6-1. | Distribution of temperature, humidity and ammonia concentration . 41
Figure 6-8. | Permutation importance for temperature and ammonia concentration 48

Figure 6-11. Web dashboard showing live sensor readings, Edge-AI forecasts,

Figure A-2. Complete system schematic showing all subsystem interconnections 58 Figure A-3. ESP32 configuration circuit used for sensor interfacing and data

Figure A-4. Sensor interfacing circuit showing DHT22 and MQ-137 connections 59

Figure A-7. Actuator control circuit showing fan and heater connections . . . . 60 Figure A-8. PCB front layout design including relay driver and LCD display

Figure A-9. PCB back layout design for the smart poultry monitoring system . 61 Figure A-10. 3D rendered view of the final assembled PCB with LCD display . . 61 Figure A-11. 3D rendered design of the protective hardware enclosure box

viii

LIST OF TABLES

ix

LIST OF ABBREVIATIONS

ADC | Analog-to-Digital Converter
AI | Artificial Intelligence
API | Application Programming Interface
AUC-ROC | Area Under the ROC Curve
BOM | Bill of Materials
DHT22 | Digital Humidity and Temperature Sensor
ESP-NOW | Espressif Protocol for Low-Power Device Communication
ESP32 | Espressif Systems Processor 32
GPIO | General Purpose Input/Output
GPU | Graphical Processing Unit
I2C | Inter-Integrated Circuit
IDE | Integrated Development Environment
IEEE | Institute of Electrical and Electronics Engineers
IoT | Internet of Things
LCD | Liquid Crystal Display
MAE | Mean Absolute Error
ML | Machine Learning
MLP | Multilayer Perceptron
MQ-137 | Gas Sensor for Ammonia Detection
MSE | Mean Squared Error
NIH | National Institutes of Health
NPR | Nepalese Rupee
NTC | Negative Temperature Coefficient
PC | Personal Computer
PMC | PubMed Central
ppm | Parts Per Million
PTC | Positive Temperature Coefficient
PTQ | Post-Training Quantization
PWM | Pulse Width Modulation
RH | Relative Humidity
ROC | Receiver Operating Characteristics
SPI | Serial Peripheral Interface
TFLite | TensorFlow Lite
TinyML | Tiny Machine Learning
UART | Universal Asynchronous Receiver-Transmitter
UI | User Interface
Wi-Fi | Wireless Fidelity

x

### 1. INTRODUCTION

The rapid growth of Internet of Things (IoT) has shaped the agricultural system particularly by monitoring and managing through use of IoT. In particular, poultry farming has benefited significantly from these advancements like introduction of smart poultry solutions that improves efficiency of production. By combining IoT sensors with data-driven techniques, it is now possible to observe and maintain the environment inside poultry houses and respond manually to changes that affect bird’s health and productivity [1], [2].

Broilers are raised in controlled environments by maintaining stable conditions for optimal growth in modern broiler farming. Parameters such as temperature, humidity and ammonia concentration directly affect the poultry health and yield of farms. Among these, ammonia is an especially important parameter because even a moderate increase can lead to respiratory problems, degradation of the immune system and lower productivity. Also temperature deviations during first week can significantly increase mortality rate, so maintaining a stable microclimate is crucial for healthy development of broiler [3], [4], [5], [6], [7].

However, in many poultry farms, environmental monitoring through IoT is applied but it is partially automatic or relies on threshold based systems. These approaches are significant upgrades from fully manual farms but they fail to provide deeper insights on harmful conditions and time based prediction for these conditions. As a result farmers only react after the environment has already become critical and has already affected the health of birds. These limitations highlights need for improvement in these system with smarter and responsive monitoring approach that can not only observe conditions, analyze and react supporting early decision making.

### 1.1. Background

Poultry farming is an important part of Nepal’s agricultural sector. In broiler production, maintaining a suitable environment inside the poultry house is important for healthy growth and good production performance. The brooding period, particularly the first two weeks after hatching, is one of the most sensitive stages, as young chicks are highly affected by changes in their surroundings. Temperature, humidity, and ammonia concentration are among the important environmental factors that affect their health and growth. Very high or low temperatures can cause stress and slow down growth, high humidity can result in poor litter conditions, and the accumulation of ammonia can cause respiratory problems and negatively affect overall productivity [8].

In Nepal, many poultry farms still use traditional open-house systems. These houses are strongly affected by outdoor weather conditions, making it difficult for farmers to maintain a stable environment inside. In many cases, farmers depend on their own experience and regular observation to check conditions and decide when management actions are needed. Although this approach can be useful, it does not provide continuous information about the actual environmental conditions, and changes in these parameters may go unnoticed until they begin to affect the chicks.

The development of sensors and wireless communication technologies has provided new possibilities for monitoring poultry house environments. IoT-based systems can collect environmental data continuously, allowing farmers to monitor conditions in real time. However, many existing systems are mainly designed to display sensor readings or provide simple alerts, offering limited analysis of the data and little support for predicting future environmental conditions [9]. Therefore, there is a need for a more effective monitoring approach capable of collecting and analyzing continuous environmental information inside poultry houses, helping farmers identify unfavorable conditions earlier and take appropriate action during the critical brooding stage of broiler production.

### 1.2. Motivation

The idea for this project came from the discussions about the bird flu outbreaks that occurred in Nepal in late May. This made us realize that poultry farming can be affected by health risks that may lead to significant losses for farmers. Although directly detecting or preventing diseases such as bird flu was beyond the scope of our minor project, we wanted to focus on an area where we could make a practical contribution. We therefore decided to improve the existing poultry farming particularly on broiler during the brooding stage by focusing on environmental conditions that can affect poultry health. Environmental parameters such as temperature, humidity and ammonia are important for maintaining suitable conditions inside a poultry house. Instead of only monitoring, we aimed to use IoT sensors to collect real-time data and machine learning analyze the data. This allows identification of possible changes in environmental conditions of the broiler in brooding stages.

The main motivation of this project is to develop a system that can provide farmers with earlier awareness of the unfavorable conditions and take appropriate actions. While the system cannot directly detect or prevent diseases such as bird flu, maintaining better environmental conditions can help to reduce the mortality rate, risk and support better farming for broilers.

### 1.3. Problem Statement

Poultry farming in Nepal commonly uses an open-house system. Such systems are strongly affected by outdoor weather and day-to-day management practices. Maintaining suitable conditions of farm is important during the first two weeks of broiler growth, as young chicks are sensitive to changes in temperature and air quality. Continuous monitoring and maintenance for environmental conditions can be difficult for farmers, particularly when they mainly depend on manual observation and experience.

Temperature and ammonia concentration are two major environmental concerns during brooding period. When the temperature and ammonia level rises beyond the safe level, chicks can experience stress, reduced growth, and higher risk of mortality. Higher ammonia levels can affect the respiratory health of birds and reduce overall productivity. Changes in humidity can make it difficult to maintain suitable litter contribution and may contribute to increased ammonia levels [10].

Although some farms use basic methods to monitor environmental conditions, continuous monitoring of temperature, humidity, and ammonia is still limited. Farmers may not always be aware of unfavorable changes as they occur, delaying the necessary response. This is particularly concerning during the brooding period. Therefore, there is a need for a system able to monitor these environmental parameters continuously, providing timely information.

### 1.4. Objectives

The main objectives of this project are as follows:

- To design and develop an IoT-based Edge-AI system for real-time monitoring, prediction, and control of environmental conditions in poultry houses, with a focus on the brooding stage of broiler production.

### 1.5. Scope and Limitations

### 1.5.1. Scope

The current project aims to develop an IoT and machine learning based system for monitoring and managing environmental conditions. The system focuses on real-time monitoring of temperature, humidity and ammonia concentration using sensors connected to an ESP32. The collected environmental data is processed and used by learning model to predict environmental changes. It notifies early warnings of potentially unsafe conditions. The system also includes automated ventilation control and web-based dashboard for real-time visualization. The application domain includes poultry-house environmental monitoring, early detection of unfavorable conditions, predictive environmental management and ventilation control. The project is mainly focused on developing and evaluating a prototype under the condition represented by collected dataset. The current scope does not include disease diagnosis, full scale commercial farm integration and poultry behavior monitoring.

### 1.5.2. Limitations

The scope of this project is limited to environmental monitoring, prediction, visualization, alerting, and ventilation control based on temperature, humidity, and ammonia levels. The performance of the machine-learning model is dependent on the quality, size, and range of the available dataset. Additional environmental parameters and advanced biological health monitoring, such as sound or image-based disease along with behavior detection are not implemented in the current system.

### 1.6. Report Organization

This report is organized into eight chapters, with each chapter covering a specific aspect of the developed smart poultry farming system. The Introduction chapter presents the background of the project, identifies the problem and describes the objective and scope of the developed system. The Literature Review chapter shares reflections on previously published projects of a similar kind. The Requirement Analysis chapter is divided into three parts: Project Requirement, System Requirement and Feasibility Analysis. The System Architecture and Methodology chapter illustrates the overall system architecture, working picture and dataflow used to develop the system. The Implementation Details chapter describes the practical implementation of the hardware and software components including the sensor integration and its interfacing along with the protocols used for communication. The Result and Analysis chapter presents the experimental results obtained from the developed system and evaluates the performance of the prediction model with the system operation. The Future Enhancements chapter discusses the possible improvements and extensions that can be incorporated into the system in future work. Finally, the Conclusion chapter summarizes the overall work, major achievements and significance of the developed system. Additional technical information including the circuit diagram, PCB diagram, module specification and other supporting materials is provided in the Appendices for reference.

### 2. LITERATURE REVIEW

### 2.1. Introduction to Poultry Farming Automation

The Internet of Things (IoT) has been integrated into poultry farming automation through the use of multiple sensors and actuators to improve environmental monitoring and farm management [3], [11]. This represents a major transition from traditional agricultural approaches toward automated and data-driven farming systems. The biological impact of microclimates plays a vital role in poultry health and mortality rates. Environmental parameters such as temperature and NH3 (ammonia gas) concentration are among the major factors that directly affect poultry growth and production performance [5], [12].

Chicks in the earliest stage of life (1-3 weeks) are extremely sensitive to microclimate variables, especially temperature and ammonia concentration. The mortality rate during this period is one of the most significant economic challenges in poultry for broilers.

Unlike adult birds, a day-old chick cannot adapt to temperature making them entirely dependent on surrounding conditions toe warm [13]. Due to this poor environmental management that allows cold stress to occur and improper handling increases first week mortality up to three times [14]. Alongside the temperature, the ammonia in the air plays another role in mortality of chicks, if the ammonia concentration reaches 25ppm, the damage to developing respiratory tracts of chicks is caused and increases susceptibility to disease and reduction in feed intake [14], [15], [16].

Therefore, continuous monitoring of these parameters is essential for maintaining a suitable poultry house environment.

### 2.2. Evolution of Architecture in IoT

The microcontroller acts as the central processing unit that processes sensor data and controls environmental actuators [3], [5]. These environmental control mechanisms commonly include ventilation systems and temperature regulation systems that operate based on monitored environmental conditions [3], [5].

Sensors such as DHT11/DHT22 for temperature and humidity monitoring and MQ-137 for ammonia gas detection are widely used in low-cost poultry automation systems [12], [17]. However, DHT22 has ± 0.5 °C of accuracy vs DHT11 has accuracy of ± 2 °C. Also, for the ammonia sensor MQ-137 is reported to have accuracy of R2 = 0.64 in real-life conditions [2]. These sensors provide sufficient environmental information while maintaining low implementation costs, making them suitable for prototype and small-scale smart poultry farming applications.

### 2.3. Limitations of Traditional Control Loop: Navigating the Flaw

Many existing poultry monitoring systems rely on threshold-based control mechanisms [3], [11]. These systems use current sensor readings to trigger environmental control actions. For example, when the temperature exceeds a predefined threshold, the ventilation fan is activated.

Although effective for basic automation, this approach remains reactive. The control mechanism responds only after unfavorable environmental conditions have already occurred. The temperature swing outside the safe range increases mortality risk in early aged chicks because they face severe thermal stress and metabolic exhaustion [14]. Consequently, poultry may be exposed to stressful conditions due to which body weight declines roughly by 6% and 9% at 50 ppm and 75 ppm respectively, compared to unexposed birds, also with mortality rising to 13.9% at 75ppm and 5.8% in unexposed environment (0 ppm) [18]. This limitation becomes particularly important in the case of ammonia accumulation, where delayed intervention may negatively affect poultry health and productivity.

### 2.4. Machine Learning in Poultry Farming Automation

Recent advancements in artificial intelligence and machine learning have enabled more intelligent approaches to poultry farm monitoring and management [4]. Unlike traditional threshold-based systems that rely solely on current sensor measurements, machine learning models can analyze historical and real-time environmental data to identify patterns and trends.

Instead of relying only on the current environmental state, the Multilayer Perceptron model can utilize a sequence of observations collected over a continuous time window. By analyzing variations in ammonia concentration, temperature, and humidity over time, the model can identify environmental trends and provide early warnings of potentially unsafe conditions before critical thresholds are reached [4]. Since the multilayer perceptron (MLP) demonstrated superior accuracy in predicting the spikes in temperature and ammonia concentrations in air compared to ML models like Decision Tree, Naive Bayes, which justifies the selection of MLP for the minor project [15].

Such predictive capabilities allow environmental control mechanisms to respond proactively rather than reactively, helping maintain a more stable poultry house environment and improving overall poultry welfare.

### 2.5. Identification of the Technical Gap

Existing literature demonstrates significant progress in IoT-based poultry monitoring systems and environmental automation [3], [11], [5]. However, most existing systems continue to focus primarily on reactive control strategies based on predefined threshold values.

While recent studies have highlighted the potential of artificial intelligence in poultry farming [4], limited research has explored the integration of low-cost IoT hardware with neural network-based models for short-term prediction of environmental conditions in poultry houses. Furthermore, the use of a continuous environmental observation window to predict potential spikes in ammonia concentration, temperature, and humidity before threshold violations has not been extensively investigated. Also, another gap that is identified is no existing low cost hardware implementation has worked on age based weekly threshold monitoring profiles despite broilers requiring specific temperature requirements changing significantly from week to week [19], [13], [17].

Therefore, this project aims to address this gap by integrating low-cost environmental sensors with a neural network model capable of analyzing environmental trends and providing early warnings of potentially unsafe conditions before they occur.

### 2.6. Availability of Datasets for Environmental Prediction

Public datasets are widely available for parameters like temperature, ammonia (NH3), humidity and more from IEEE DataPort [20] and (PMC), a repository maintained by the National Institutes of Health (NIH) [21] for analysis of correlation and to establish a realistic environment for broilers. Also, the closely related datasets involve MDPI [22] datasets which involve the parameters required for us.

### 3. REQUIREMENT ANALYSIS

### 3.1. Project Requirement

The project requirement are categorized into functional and non-functional requirement to ensure that system meets its intended purpose objective. These requirements describes the core functionality and quality attributes along with operational characteristics. This ensured the system operates reliably and as expected during implementation.
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

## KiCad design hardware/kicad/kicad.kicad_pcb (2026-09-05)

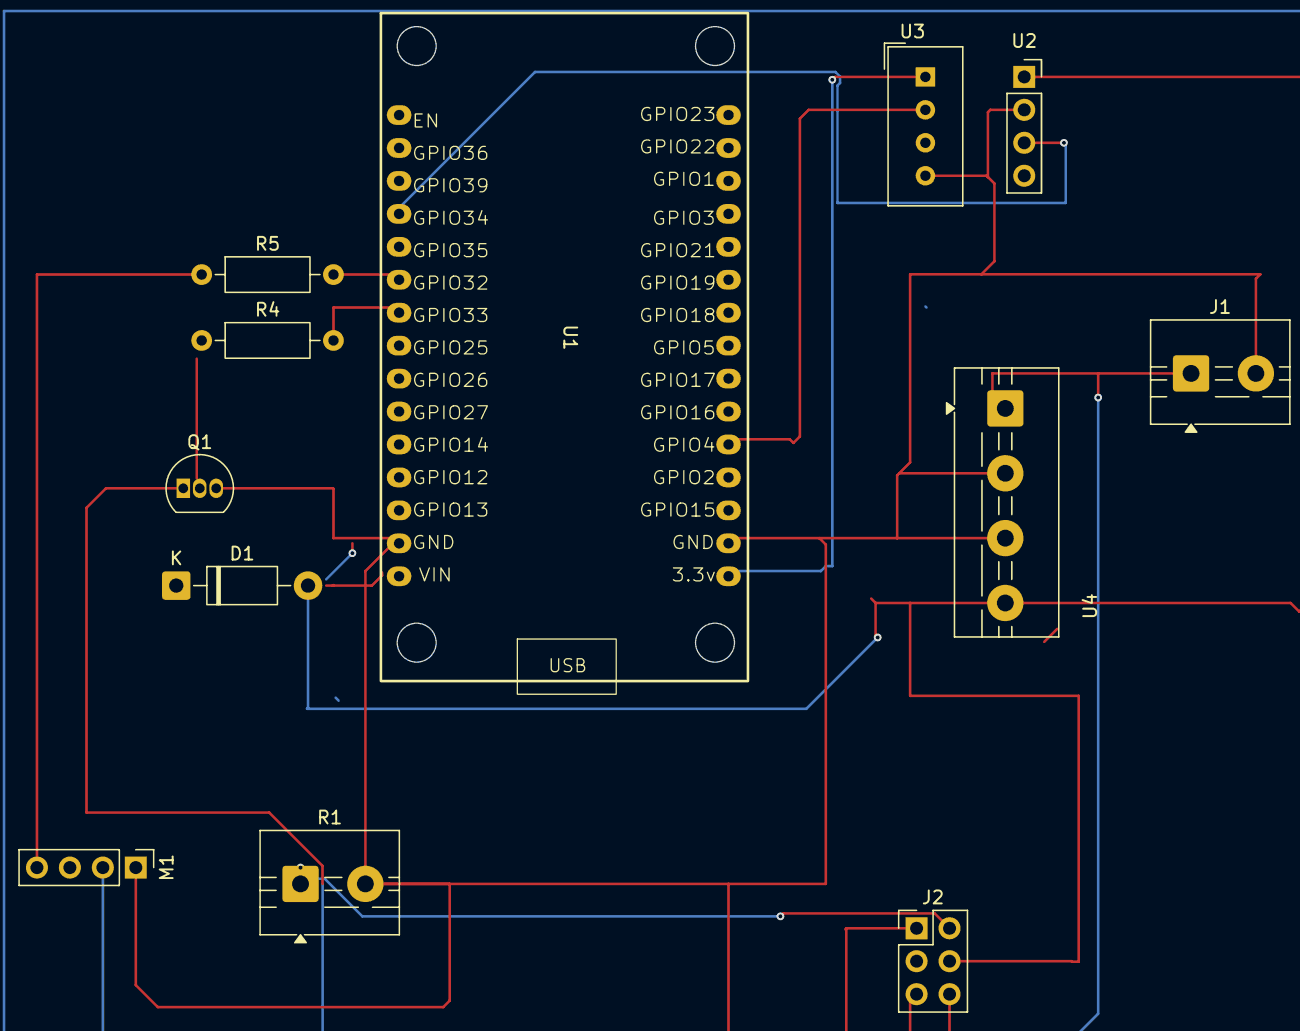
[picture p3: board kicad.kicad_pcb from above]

Board: 2 copper layers, 12 parts (0 on the bottom side), 13 nets.

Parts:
D1: 1N4007; D_DO-41_SOD81_P10.16mm_Horizontal
J1: 12V-input; TerminalBlock_MaiXu_MX126-5.0-02P_1x02_P5.00mm
J2: Conn_01x03_Pin; PinHeader_2x03_P2.54mm_Vertical
M1: Fan_4pin; PinHeader_1x04_P2.54mm_Vertical
Q1: BC547; TO-92_Inline
R1: Heater; TerminalBlock_MaiXu_MX126-5.0-02P_1x02_P5.00mm
R4: 1K; R_Axial_DIN0207_L6.3mm_D2.5mm_P10.16mm_Horizontal
R5: 200; R_Axial_DIN0207_L6.3mm_D2.5mm_P10.16mm_Horizontal
U1: ESP32_30pin
U2: MQ-137; PinSocket_1x04_P2.54mm_Vertical
U3: DHT22; Aosong_DHT11_5.5x12.0_P2.54mm
U4: DCDC_StepDown_LM2596; TerminalBlock_MaiXu_MX126-5.0-04P_1x04_P5.00mm

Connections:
+3.3V: U1.16 (3.3v), U3.1 (VCC)
+5V: D1.2 (A), J2.4 (VCC), U2.1 (VCC), U4.4 (Vout)
+12V: J1.1, J2.1 (COM), M1.2 (+), U4.1 (Vin)
/DHT_DATA: U1.20 (GPIO4), U3.2 (DATA)
/MQ_DATA: U1.12 (GPIO34), U2.3 (A0)
/PWM_FAN: M1.4 (PWM), R5.1
/PWM_HEATER: Q1.2 (B), R4.1
GND: J1.2, J2.5 (GND), M1.1 (-), Q1.3 (E), R1.2, U1.2 (GND), U1.17 (GND), U2.2 (GND), U3.4 (GND), U4.2 (GND), U4.3 (GND)
unnamed: D1.1 (K), U1.1 (VIN)
unnamed: J2.6 (IN), Q1.1 (C)
unnamed: J2.2 (NO), R1.1
unnamed: R4.2, U1.8 (GPIO25)
unnamed: R5.2, U1.10 (GPIO32)

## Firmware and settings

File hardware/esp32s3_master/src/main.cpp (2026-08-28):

// ============================================================================
// main.cpp -- ESP32-S3 master node firmware.
//
// Responsibilities:
//   1. Connect to WiFi, print own MAC address (needed to configure sensor
//      node), and sync NTP -- the sole source of wall-clock time for the
//      model's hour-of-day feature now, since the sensor node has no WiFi
//      of its own (see esp32/include/config.h's "Radio" section).
//   2. Register as ESP-NOW receiver; accept SensorPacket from the sensor
//      ESP32. If none arrives for 3x its expected interval, self-heal by
//      re-initializing ESP-NOW (see the watchdog block in loop()).
//   3. On each received packet, POST the data to the Django telemetry API.
//   4. Parse the HTTP 201 response to extract predicted_class.
//   5. Send ActuatorCommand back to the sensor ESP32 over ESP-NOW so it can
//      drive fan/heater actuators to close the control loop.
//
// Boot sequence:
//   a) Flash this firmware first.
//   b) Open Serial Monitor -- the board prints:
//        [BOOT] Master MAC: AA:BB:CC:DD:EE:FF
//   c) Copy that MAC into esp32/include/config.h as MASTER_MAC_ADDR.
//   d) Flash the sensor ESP32 firmware.
//   e) Both boards are now running; sensor packets arrive every 5 s and
//      the dashboard shows real sensor data.
// ============================================================================

#include <Arduino.h>
#include <WiFi.h>
#include <WiFiUdp.h>
#include <HTTPClient.h>
#include <esp_now.h>
#include <ArduinoJson.h>
#include <time.h>  // getLocalTime() -- see currentHour() below
#include <esp_system.h>  // esp_reset_reason() -- see logResetReason() below

#include "config.h"
#include "model_runner.h"

// ----------------------------------------------------------------------------
// State
// ----------------------------------------------------------------------------
// Last SensorPacket received over ESP-NOW, handed off from the WiFi-task
// context (ESP-NOW callback) to loop() via a critical section.
static SensorPacket  g_packet;
static volatile bool g_newPacket  = false;
static uint8_t       g_sensorMac[6] = {0};
static bool          g_sensorKnown  = false;
static portMUX_TYPE  g_mux = portMUX_INITIALIZER_UNLOCKED;

// millis() timestamp of the last SensorPacket actually received, and of the
// last watchdog-triggered ESP-NOW re-init -- see the silence check in
// loop(). Seeded at the end of setup() (not left at 0/epoch) so the
// silence window starts counting from this board's own boot, giving the
// sensor node time to boot and start transmitting before being flagged.
static uint32_t g_lastPacketRxMs = 0;

// Django host, found via UDP broadcast discovery instead of a hardcoded IP
// (see discoverDjangoHost() below). Empty/unknown until discovery succeeds.
static String         g_djangoHost  = "";
static bool           g_djangoKnown = false;

// Last classification string relayed to the sensor node -- used only as the
// `state` field on the ActuatorCommand sent by pollManualControl() below
// (the sensor no longer acts on `state`, only logs it, so staleness here is
// cosmetic). Updated whenever a real ingestion round-trip succeeds.
static char g_lastState[24] = "OPTIMAL_ENVIRONMENT";

// Last successful on-device model prediction, cached so the independent
// MANUAL-override poll below (which runs on its own timer, decoupled from
// sensor packets) can still relay it to the sensor node's LCD instead of
// blanking the "Predicted" screen back to a warm-up placeholder every time
// a MANUAL command goes out.
static ModelPrediction g_lastPrediction;
static bool            g_havePrediction = false;

// Flock age in weeks, synced from Django's FlockProfile via the independent
// CONTROL_PATH poll below (see fetchManualControl()'s age_weeks parsing) --
// the retrained on-device model takes flock age as a feature ("week" in
// feature_cols), so the master needs it locally even though inference runs
// before this sample is ever POSTed to Django. Defaults to 1 (youngest
// band) until the first successful poll after boot.
static uint8_t g_flockAgeWeeks = 1;

// Forward declarations -- ensureWifi() (below) needs to re-run ESP-NOW
// bring-up after a reconnect, but initEspNow()/registerSensorPeer() are
// defined further down alongside the rest of the ESP-NOW callbacks.
static bool initEspNow();
static void registerSensorPeer();

// ----------------------------------------------------------------------------
// WiFi helpers
// ----------------------------------------------------------------------------
static void connectWifi() {
    WiFi.mode(WIFI_STA);
    WiFi.setSleep(false);
    WiFi.begin(WIFI_SSID, WIFI_PASSWORD);

    Serial.printf("[WIFI] Connecting to '%s'...\n", WIFI_SSID);
    for (int i = 0; i < WIFI_MAX_RETRIES; ++i) {
        if (WiFi.status() == WL_CONNECTED) {
            Serial.printf("[WIFI] Connected. IP=%s  Channel=%d  RSSI=%d dBm\n",
                          WiFi.localIP().toString().c_str(),
                          WiFi.channel(), WiFi.RSSI());
            // The sensor node hardcodes its ESP-NOW channel (it has no AP
            // to negotiate one from -- see esp32/include/config.h's
            // "Radio" section) instead of following this router
            // dynamically. If the router ever assigns a different channel
            // than the sensor is fixed to, ESP-NOW between the two boards
            // goes silently dead -- flag it loudly here since there's
            // nothing this board can do about it besides tell the operator.
            if (WiFi.channel() != ESPNOW_WIFI_CHANNEL) {
                Serial.printf("[WIFI] WARNING: router assigned channel %d but the "
                              "sensor node is hardcoded to channel %d "
                              "(ESPNOW_WIFI_CHANNEL, esp32/include/config.h) -- "
                              "ESP-NOW will NOT work until these match. Update the "
                              "sensor's config.h and reflash it, or fix the "
                              "router's channel.\n",
                              WiFi.channel(), ESPNOW_WIFI_CHANNEL);
            }
            return;
        }
        delay(WIFI_RETRY_MS);
        Serial.printf("[WIFI] retry %d/%d\n", i + 1, WIFI_MAX_RETRIES);
    }
    Serial.println("[WIFI] Failed to connect.");
}

static void ensureWifi() {
    if (WiFi.status() == WL_CONNECTED) return;
    Serial.println("[WIFI] Link lost -- reconnecting.");
    WiFi.disconnect(true, true);
    connectWifi();

    // Re-init ESP-NOW after WiFi reconnect (channel may have changed).
    // CRITICAL: esp_now_deinit() wipes BOTH the registered send/recv
    // callbacks (only ever set up once, in initEspNow() from setup()) AND
    // the peer table -- if either isn't redone here, the board goes
    // silently deaf (never fires onDataRecv for incoming SensorPackets) or
    // mute (esp_now_send() to the now-unregistered sensor peer fails) over
    // ESP-NOW, permanently, until the next full power-cycle. This is the
    // most likely failure mode on a board running off external/battery
    // power where WiFi drops (brownouts, AP roaming, signal dropouts) are
    // routine rather than rare -- a board on USB power during development
    // may simply never hit this path, masking the bug until field
    // deployment. initEspNow() re-registers the callbacks; if the sensor's
    // MAC was already learned from an earlier packet, registerSensorPeer()
    // re-adds it so ActuatorCommands (fan/heater duty, LCD predictions)
    // can keep flowing back to it too.
    esp_now_deinit();
    if (!initEspNow()) {
        Serial.println("[ESPNOW] Re-init after WiFi reconnect failed -- "
                        "sensor RX and actuator relay are down until next reset.");
    } else if (g_sensorKnown) {
        registerSensorPeer();
    }

    // A reconnect can mean a new DHCP lease -- possibly for the Django PC
    // too -- so don't trust the previously-discovered host anymore.
    g_djangoKnown = false;
}

// Last-known local hour, used as a fallback if NTP hasn't synced (or has
// lapsed) so the model's hour_sin/hour_cos cyclic features stay in a
// plausible (not pathological) range rather than going stale forever.
// Seeded to a neutral noon default, same fallback pattern the sensor node
// used to use for its own now-removed currentHourMonth().
static uint8_t g_lastHour = 12;

/**
 * Read current local hour for the model's hour_sin/hour_cos cyclic
 * features. The sensor node has no WiFi/NTP of its own anymore (see
 * esp32/include/config.h's "Radio" section) -- this board is the only one
 * with a wall-clock, so it now supplies hour itself instead of trusting a
 * value in the SensorPacket (which no longer carries one at all). Falls
 * back to the last successfully-read hour rather than propagating a hard
 * failure, since inference must not stall on a clock read.
 */
static uint8_t currentHour() {
    struct tm timeinfo;
    if (getLocalTime(&timeinfo, 0)) {
        g_lastHour = static_cast<uint8_t>(timeinfo.tm_hour);
    }
    return g_lastHour;
}

// ----------------------------------------------------------------------------
// ESP-NOW callbacks
// ----------------------------------------------------------------------------
static void onDataRecv(const uint8_t *mac_addr, const uint8_t* data, int len) {
    if (len != sizeof(SensorPacket)) return;

    portENTER_CRITICAL_ISR(&g_mux);
    memcpy(&g_packet, data, sizeof(SensorPacket));
    g_newPacket = true;

    // Auto-learn sensor MAC on first packet so we can send ActuatorCommand back.
    if (!g_sensorKnown) {
        memcpy(g_sensorMac, mac_addr, 6);
        g_sensorKnown = true;
    }
    portEXIT_CRITICAL_ISR(&g_mux);
}

static void onDataSent(const uint8_t* /*mac*/, esp_now_send_status_t status) {
    if (status != ESP_NOW_SEND_SUCCESS) {
        Serial.println("[ESPNOW] ActuatorCommand delivery failed.");
    }
}

static bool initEspNow() {
    if (esp_now_init() != ESP_OK) {
        Serial.println("[ESPNOW] Init failed.");
        return false;
    }
    esp_now_register_recv_cb(onDataRecv);
    esp_now_register_send_cb(onDataSent);
    Serial.println("[ESPNOW] Listening for sensor packets.");
    return true;
}

// Register the sensor node as a peer once its MAC is known (first packet).
static void registerSensorPeer() {
    esp_now_peer_info_t peer = {};
    memcpy(peer.peer_addr, g_sensorMac, 6);
    peer.channel = 0;
    peer.encrypt = false;
    if (esp_now_add_peer(&peer) == ESP_OK) {
        Serial.printf("[ESPNOW] Sensor peer registered: %02X:%02X:%02X:%02X:%02X:%02X\n",
                      g_sensorMac[0], g_sensorMac[1], g_sensorMac[2],
                      g_sensorMac[3], g_sensorMac[4], g_sensorMac[5]);
    }
}
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
void loop() {
    ensureWifi();

    // Sensor silence watchdog: if no SensorPacket has arrived in 3x the
    // sensor's expected transmission interval, the ESP-NOW stack itself may
    // be stuck without this board's own WiFi ever having dropped (the case
    // ensureWifi()'s reconnect-triggered re-init above doesn't cover). Cheap
    // self-heal: re-run the identical esp_now_deinit()/initEspNow()/
    // registerSensorPeer() sequence. Harmless no-op if the sensor is
    // genuinely powered off -- it just keeps retrying every window; doesn't
    // touch the model's bucket history, so a brief real outage doesn't cost
    // the ~70 min warm-up.
    {
        static uint32_t lastWatchdogRecoveryMs = 0;
        const uint32_t sinceLastPacket = millis() - g_lastPacketRxMs;
        if (sinceLastPacket > SENSOR_SILENCE_TIMEOUT_MS &&
            millis() - lastWatchdogRecoveryMs > SENSOR_SILENCE_TIMEOUT_MS) {
            lastWatchdogRecoveryMs = millis();
            Serial.printf("[ESPNOW] No sensor packet in %lu ms (>= 3x expected "
                          "interval) -- re-initializing ESP-NOW.\n",
                          (unsigned long)sinceLastPacket);
            esp_now_deinit();
            if (!initEspNow()) {
                Serial.println("[ESPNOW] Watchdog re-init failed -- will retry next window.");
            } else if (g_sensorKnown) {
                registerSensorPeer();
            }
        }
    }

    // Keep trying to (re)discover the Django host in the background --
    // covers "Django hadn't started yet at boot" and "its IP just changed"
    // without hammering the network with broadcasts every iteration.
    if (!g_djangoKnown) {
        static uint32_t lastAttemptMs = 0;
        if (millis() - lastAttemptMs > 5000) {
            lastAttemptMs = millis();
            g_djangoKnown = discoverDjangoHost();
        }
    }

    // Independent MANUAL-override poll, decoupled from sensor-packet arrival
    // -- without this, a dashboard MANUAL fan/heater command would only ever
    // reach the sensor node piggybacked on a fresh SensorPacket below, which
    // means it silently never fires while the sensor node is offline (see
    // fetchManualControl() doc comment). Runs on its own CONTROL_POLL_MS
    // cadence, independent of g_newPacket.
    {
        static uint32_t lastControlPollMs = 0;
        if (g_sensorKnown && millis() - lastControlPollMs > CONTROL_POLL_MS) {
            lastControlPollMs = millis();
            uint8_t manualFanPwm = 0, manualHeaterPwm = 0;
            if (fetchManualControl(manualFanPwm, manualHeaterPwm)) {
                Serial.printf("[CONTROL] Independent poll -- MANUAL fan_pwm=%u heater_pwm=%u (state=%s)\n",
                              manualFanPwm, manualHeaterPwm, g_lastState);
                sendActuatorCommand(g_lastState, manualFanPwm, manualHeaterPwm,
                                    g_havePrediction ? &g_lastPrediction : nullptr);
            }
        }
    }

    if (!g_newPacket) return;

    // Safely copy the packet out of the ISR-shared buffer.
    SensorPacket pkt;
    portENTER_CRITICAL(&g_mux);
    pkt = g_packet;
    g_newPacket = false;
    portEXIT_CRITICAL(&g_mux);
    g_lastPacketRxMs = millis();  // Feeds the silence watchdog above.

    // Auto-register sensor as ESP-NOW peer on first packet.
    static bool peerAdded = false;
    if (g_sensorKnown && !peerAdded) {
        registerSensorPeer();
        peerAdded = true;
    }

    Serial.printf("[RX] seq=%u T=%.1fC RH=%.1f%% NH3=%.1fppm\n",
                  pkt.seq, pkt.temperature, pkt.humidity, pkt.ammonia_ppm);

    // Run on-device inference. Each raw sample feeds a rolling 10-minute
    // bucket internally (see model_runner.cpp) -- returns false almost every
    // call, and only ever produces a fresh prediction once each ~10-minute
    // bucket finalizes, needing 7 finalized buckets (~70 min after boot)
    // before the first one. hour comes from this board's own clock now
    // (currentHour() above), not the packet -- see RawSample's doc comment.
    RawSample raw{pkt.temperature, pkt.humidity, pkt.ammonia_ppm, currentHour()};
    ModelPrediction pred;
    const bool havePrediction = model_runner::predict(raw, g_flockAgeWeeks, pred);
    if (havePrediction) {
        Serial.printf("[MODEL] next T=%.2fC NH3=%.2fppm ammonia_spike_prob=%.4f(%d) temp_spike_prob=%.4f(%d)\n",
                      pred.temperature_next, pred.ammonia_next,
                      pred.ammonia_spike_probability, pred.ammonia_spike_predicted,
                      pred.temp_spike_probability, pred.temp_spike_predicted);
        g_lastPrediction = pred;
        g_havePrediction = true;
    } else {
        Serial.println("[MODEL] warming up -- not enough bucketed history yet (~70 min after boot).");
    }

    // Fan PWM duty (0-255) from predicted-NH3 error. 0 (fan off) while the
    // model is still warming up and havePrediction is false. Sent verbatim
    // to the sensor node, whose fan is real PWM.
    uint8_t fanPwm = 0;
    if (havePrediction) {
        float nh3_error = pred.ammonia_next - 5.0f;        // setpoint = 5 ppm
        if (nh3_error < 0) nh3_error = 0;
        int pwm = (int)((nh3_error / 25.0f) * 255);        // scale 0-25 ppm error -> 0-255
        fanPwm = (uint8_t)constrain(pwm, 0, 255);
    }

    // POST to Django and get classification.
    char state[24] = "OPTIMAL_ENVIRONMENT";
    static uint8_t consecutiveFailures = 0;
    bool manualMode = false;
    uint8_t manualFanPwm = 0;
    uint8_t manualHeaterPwm = 0;   // NEW
    bool lowTemperatureAlert = false;
    if (postToDjango(pkt, havePrediction ? &pred : nullptr, state, manualMode, manualFanPwm, manualHeaterPwm,
                      lowTemperatureAlert)) {
        consecutiveFailures = 0;
        strncpy(g_lastState, state, sizeof(g_lastState) - 1);  // for the independent MANUAL poll's log/state field
        Serial.printf("[TX] Classification: %s -- sending ActuatorCommand to sensor.\n", state);
    } else {
        Serial.println("[TX] HTTP failed; sending last-known state to sensor.");
        // A handful of failures against a "known" host most likely means the
        // Django PC's IP changed underneath us (new DHCP lease) -- rather
        // than fail forever, drop it and let loop() re-discover.
        if (g_djangoKnown && ++consecutiveFailures >= 3) {
            Serial.println("[DISCOVERY] Repeated POST failures -- re-discovering Django host.");
            g_djangoKnown = false;
            consecutiveFailures = 0;
        }
    }

    // Heater PWM byte -- driven by lowTemperatureAlert (a raw temperature-
    // vs-threshold check Django computes independently), NOT by checking
    // state=="LOW_TEMP_ALERT". state is a single mutually-exclusive label
    // with ammonia checked first (see classify_environment() in
    // telemetry/classifier.py), so a reading that's simultaneously
    // CRITICAL_AMMONIA and genuinely cold comes back with
    // state=="CRITICAL_AMMONIA" -- checking state alone here would then
    // leave the heater off exactly when a chick is both gassed and
    // freezing. lowTemperatureAlert sidesteps that masking entirely (see
    // the postToDjango() doc comment and ActuatorControl.auto_duty_for_state()
    // in telemetry/models.py for the full reasoning).
    uint8_t heaterPwm = lowTemperatureAlert ? 255 : 0;

    // Safety floor: a live reading already past threshold forces the fan to
    // 100% regardless of what the forecast says -- mirrors
    // ActuatorControl.auto_duty_for_state() in telemetry/models.py. Until
    // this, that floor existed ONLY as a number Django computed for the
    // dashboard's AUTO display; it never reached this fanPwm calculation
    // (which only ever looks at pred.ammonia_next above, never `state`), so
    // a live CRITICAL_AMMONIA/HEAT_STRESS_WARNING reading with a low
    // forecast left the dashboard reading "Fan 100%" while the physical fan
    // sat near idle. A reading already past a safety threshold must not
    // wait on a prediction to react.
    if (strcmp(state, "CRITICAL_AMMONIA") == 0 || strcmp(state, "HEAT_STRESS_WARNING") == 0) {
        fanPwm = 255;
    }

    // Dashboard MANUAL override (fan speed + heater power sliders) wins over
    // the on-device MLP-predicted fanPwm and the classification-derived
    // heaterPwm computed above. AUTO leaves both as-is.
    if (manualMode) {
        Serial.printf("[CONTROL] Dashboard MANUAL override -- fan_pwm=%u (was predicted %u)  heater_pwm=%u (was %u)\n",
                      manualFanPwm, fanPwm, manualHeaterPwm, heaterPwm);
        fanPwm = manualFanPwm;
        heaterPwm = manualHeaterPwm;
    }
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

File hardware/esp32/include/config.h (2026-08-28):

// ============================================================================
// config.h -- Compile-time configuration for the ESP32 edge node.
//
// All hardware-specific magic numbers live here. Pin assignments mirror the
// KiCad schematic (2x15 pin socket, ESP32 DevKit V1); do not change without
// updating the board layout and this comment block simultaneously.
// ============================================================================
#pragma once

// ---------------------------------------------------------------------------
// Radio -- ESP-NOW only, no WiFi AP join
// ---------------------------------------------------------------------------
// This node has no network credentials and never associates with any WiFi
// access point -- it only uses the WiFi radio hardware to speak ESP-NOW
// directly to the ESP32-S3 master (see HARDWARE_DOCUMENTATION.md "ESP-NOW
// pipeline"). It doesn't talk to Django, doesn't get an IP, and doesn't sync
// NTP; the master owns the WiFi/HTTP leg to Django and is now also the
// source of wall-clock time for the model's hour-of-day cyclic feature (see
// currentHour() in esp32s3_master/src/main.cpp) since this board no longer
// has a clock of its own.
//
// ESP-NOW requires both peers' radios on the SAME WiFi channel. Previously
// this board guaranteed that by joining the same AP as the master and
// letting the router assign the channel to both; without an AP join, the
// channel has to be fixed at compile time instead:
#define ESPNOW_WIFI_CHANNEL 2
// ^ Must match whatever channel the ESP32-S3 master's WiFi actually lands
// on -- check the master's boot log line "[WIFI] Connected. IP=... Channel=N
// ...". Updated 2026-08-28 to 2 for the "ASUS_FC" network. Routers with
// auto-channel-select can change this later (e.g. after a reboot or
// interference-driven reshuffle) -- if ESP-NOW packets silently stop
// arriving at the master despite this board's [TX] lines looking normal,
// check the master's actual channel first. The master logs a boot-time
// warning if its own channel doesn't match this value, but can't fix a
// mismatch itself -- update this constant and reflash this board if it
// happens.

// MAC address of the ESP32-S3 master node's WiFi station interface. Flash
// esp32s3_master/ first and copy the "[BOOT] Master MAC (WiFi STA): XX:XX:XX:XX:XX:XX"
// line it prints on boot into this array (byte order matches, no reversal
// needed). Read back live from the currently-flashed master board on
// 2026-08-07: DC:B4:D9:14:14:6C. Re-copy this if the master is ever
// reflashed onto different hardware (a new board has a different MAC).
#define MASTER_MAC_ADDR { 0xDC, 0xB4, 0xD9, 0x14, 0x14, 0x6C }

// ---------------------------------------------------------------------------
// Timing
// ---------------------------------------------------------------------------
// Transmit cadence must match the dashboard's polling interval (5 s) so the
// chart tail advances one point per refresh -- no aliasing or empty ticks.
#define SAMPLE_INTERVAL_MS 5000

// BENCHMARK_MODE only (see platformio.ini's esp32dev_benchmark environment
// and sampleBenchmark() in main.cpp). How many samples each synthetic
// scenario holds/ramps its target values over before advancing to the next
// -- 24 samples * SAMPLE_INTERVAL_MS(5s) = 2 minutes per scenario, generous
// enough to clear the master's ~9-sample (~45s) model warm-up window and
// still collect several predictions once warmed up.
#define BENCHMARK_SAMPLES_PER_SCENARIO 24

// ---------------------------------------------------------------------------
// Pin map (mirrors schematic; do not divorce)
// ---------------------------------------------------------------------------
// DHT11 data line. GPIO4 is a general-purpose IO with hardware pull-up
// support -- the standard 10 kOhm pull-up between DATA and 3V3 is assumed
// on the sensor breakout.
#define PIN_DHT_DATA    4

// MQ-137 analog output. GPIO34 is INPUT-ONLY on the classic ESP32 and is
// wired to ADC1 channel 6 -- ADC1 is the only ADC block usable while the
// WiFi radio is active, so this channel selection is mandatory, not
// incidental (this board keeps its radio on continuously for ESP-NOW even
// though it never joins an AP -- see the Radio section above). Sensor
// output must be scaled to 0-3.3 V by an external divider before reaching
// this pin; MQ modules that swing to 5 V will damage the SoC.
#define PIN_MQ_DATA     34

// Fan PWM output (speed target). Series 200 Ohm gate resistor (R5) is on
// the board. LEDC channel 0 drives this; frequency and resolution below.
#define PIN_PWM_FAN     32
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

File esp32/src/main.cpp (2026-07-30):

// ============================================================================
// main.cpp -- Poultry Telemetry ESP32 sensor-node firmware.
//
// Responsibilities, in order of execution priority:
//   1. Maintain WiFi association; reconnect with linear back-off on drop.
//      (Needed only for channel alignment with the ESP32-S3 master and for
//      NTP time -- see the network note in config.h. This node no longer
//      speaks HTTP to Django; the master owns that leg.)
//   2. Sample DHT22 (temperature, humidity) and MQ-137 (ammonia PPM) on a
//      fixed 5 s cadence.
//   3. Send a compact binary SensorPacket over ESP-NOW to the ESP32-S3
//      master node, which runs the TFLite Micro forecast/spike model and
//      forwards the combined record to Django.
//   4. Receive the resulting classification back from the master over
//      ESP-NOW and drive the PWM_FAN / PWM_HEATER outputs accordingly,
//      closing the environmental control loop end-to-end across two boards.
//
// The main loop is non-blocking; all timing is millis()-based.
// ============================================================================

#include <Arduino.h>
#include <WiFi.h>
#include <esp_now.h>
#include <time.h>
#include <DHT.h>
#include <math.h>

#include "config.h"

// ----------------------------------------------------------------------------
// Peripheral objects
// ----------------------------------------------------------------------------
static DHT dht(PIN_DHT_DATA, DHT22);

// Millis() timestamp of the last completed sample cycle. Deliberately
// separate from FreeRTOS timers so the schedule survives temporary WiFi
// stalls without drift accumulating on the reconnect side.
static uint32_t nextSampleAt = 0;
static uint32_t txSeq = 0;

// ----------------------------------------------------------------------------
// Wire contract shared with esp32s3_master/esp32s3_inference_receiver.ino.
// Field order/types must stay byte-identical on both sides -- this struct
// is copied directly out of the ESP-NOW payload with memcpy, no serializer.
// ----------------------------------------------------------------------------
struct SensorPacket {
    uint32_t seq;
    float temperature;
    float humidity;
    float ammonia_ppm;
    uint8_t hour;   // 0-23, local time
    uint8_t month;  // 1-12
};

// Classification vocabulary the master relays back -- must remain
// byte-identical to the Django telemetry.EnvironmentalState enum.
struct ActuatorCommand {
    char state[24];
};

static constexpr const char* STATE_OPTIMAL  = "OPTIMAL_ENVIRONMENT";
static constexpr const char* STATE_HEAT     = "HEAT_STRESS_WARNING";
static constexpr const char* STATE_LOW_TEMP = "LOW_TEMP_ALERT";
static constexpr const char* STATE_CRITICAL = "CRITICAL_AMMONIA";

static uint8_t masterMac[6] = MASTER_MAC_ADDR;

// Latest actuator command from the master, handed off from the ESP-NOW recv
// callback (runs in the WiFi task context) to the main loop via a critical
// section -- same pattern the master firmware uses for its own inbound path.
static ActuatorCommand g_lastCommand;
static volatile bool g_newCommand = false;
static portMUX_TYPE g_mux = portMUX_INITIALIZER_UNLOCKED;

// Last-known wall-clock fields, used as a fallback if NTP sync fails so the
// model's cyclic features stay in a plausible (not pathological) range.
static uint8_t lastHour = 12;
static uint8_t lastMonth = 6;

// ============================================================================
// WiFi lifecycle
// ============================================================================
static void connectWifi() {
    WiFi.mode(WIFI_STA);
    WiFi.setSleep(false);  // Latency over power savings for control loop.
    WiFi.begin(WIFI_SSID, WIFI_PASSWORD);

    Serial.printf("[WIFI] Associating with SSID '%s'\n", WIFI_SSID);
    for (int attempt = 0; attempt < WIFI_MAX_RETRIES; ++attempt) {
        if (WiFi.status() == WL_CONNECTED) {
            Serial.printf("[WIFI] Link up. IP=%s RSSI=%d dBm Channel=%d\n",
                          WiFi.localIP().toString().c_str(), WiFi.RSSI(), WiFi.channel());
            return;
        }
        delay(WIFI_RETRY_MS);
        Serial.printf("[WIFI] retry %d/%d\n", attempt + 1, WIFI_MAX_RETRIES);
    }
    Serial.println("[WIFI] Association failed; will retry on next tick.");
}

static void ensureWifi() {
    if (WiFi.status() == WL_CONNECTED) return;
    Serial.println("[WIFI] Link lost -- reconnecting.");
    WiFi.disconnect(true, true);
    connectWifi();
}

/**
 * Sync wall-clock time over NTP. Only meaningful while WiFi is associated;
 * called once at boot and again on every reconnect since a dropped link may
 * have let the RTC drift uncorrected for a while.
 */
static void syncNtpTime() {
    configTime(GMT_OFFSET_SEC, DAYLIGHT_OFFSET_SEC, NTP_SERVER);
    struct tm timeinfo;
    if (getLocalTime(&timeinfo, NTP_SYNC_TIMEOUT_MS)) {
        Serial.printf("[NTP] Synced: %04d-%02d-%02d %02d:%02d:%02d\n",
                      timeinfo.tm_year + 1900, timeinfo.tm_mon + 1, timeinfo.tm_mday,
                      timeinfo.tm_hour, timeinfo.tm_min, timeinfo.tm_sec);
    } else {
        Serial.println("[NTP] Sync failed -- hour/month features will use last-known/default values.");
    }
}

/**
 * Read current local hour/month for the model's cyclic features. Falls back
 * to the last successfully-read values (seeded to a neutral noon/June
 * default) rather than propagating a hard failure, since sensor sampling
 * must not stall on a clock read.
 */
static void currentHourMonth(uint8_t& hour, uint8_t& month) {
    struct tm timeinfo;
    if (getLocalTime(&timeinfo, 0)) {
        lastHour = static_cast<uint8_t>(timeinfo.tm_hour);
        lastMonth = static_cast<uint8_t>(timeinfo.tm_mon + 1);
    }
    hour = lastHour;
    month = lastMonth;
}

// ============================================================================
// Sensor sampling
// ============================================================================

/**
 * Read DHT22. The library returns NAN on checksum failure or if polled
 * faster than the sensor's 500 ms internal refresh; both cases signal an
 * invalid tick to the caller.
 */
static bool sampleDht(float& temperatureC, float& humidityPct) {
    humidityPct  = dht.readHumidity();
    temperatureC = dht.readTemperature();  // Celsius by default.
    if (isnan(humidityPct) || isnan(temperatureC)) {
        Serial.println("[DHT] Read failed -- checksum or timing violation.");
        return false;
    }
    return true;
}
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

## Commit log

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2026-07-30 Add ESP-NOW master-node pipeline with on-device spike-risk prediction
    Sensor node (esp32/) now sends readings to a new ESP32-S3 master node
    (esp32s3_master/) over ESP-NOW instead of POSTing to Django directly. The
    master runs an on-device TFLite Micro model to forecast next-tick
    temperature/ammonia and an ammonia-spike probability, forwards the combined
    record to Django, and relays the resulting classification back to the
    sensor node over ESP-NOW so it can still drive its own fan/heater.
    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
2026-07-30 feat: ESP32-S3 master PlatformIO firmware + credentials security fix
    - Move WiFi credentials to gitignored credentials.h (both boards)
    - Add credentials.h.example templates for safe repo sharing
    - Create esp32s3_master/platformio.ini for YD-ESP32-S3 board
    - Write esp32s3_master/src/main.cpp: ESP-NOW receiver, HTTP POST to
    Django, ActuatorCommand relay back to sensor node
    - Auto-learns sensor MAC from first received packet (no manual config)
    - Boot prints Master MAC so user can configure MASTER_MAC_ADDR in sensor
    - Update .gitignore to exclude all credentials.h and S3 .pio/ dirs
    [config.h, main.cpp]
2026-07-30 feat: chart scroll/pan controls + windowed rendering
    - Add ← Older / Window selector / Newer → / Latest controls to temp chart
    - Store all historical points in memory; render only a configurable window
    - Default window: 200 pts, options: 50/100/200/500/All
    - Pan buttons scroll 50 pts per click; offset resets on Latest
    - Range info label shows current slice (e.g. 511-710 / 710)
    - Add CSS for chart-scroll-bar controls
2026-07-30 fix: ESP-NOW callback signature for Arduino-ESP32 framework compatibility
    - Use const uint8_t *mac_addr (old API) instead of esp_now_recv_info_t
    - Replace deprecated StaticJsonDocument with JsonDocument (ArduinoJson v7)
    - Both esp32 and esp32s3_master firmware now compile clean
    [main.cpp]
2026-08-07 feat: hardware discovery, proportional fan control, heater relay conversion
    Squashes the session's work into one snapshot on a new branch.
    Networking / hosting:
    - Django dev server now binds 0.0.0.0 (was 127.0.0.1-only, unreachable
    from hardware on the LAN).
    - New telemetry/discovery.py: UDP broadcast responder so the ESP32-S3
    master finds the Django host's IP at runtime instead of a hardcoded
    address baked into firmware -- works unmodified across network changes.
    - ALLOWED_HOSTS loosened to "*" (dev-only) to match -- no more hardcoded
    IP to edit there either.
    - hardware/ reorganized: esp32/ and esp32s3_master/ moved under
    hardware/, esp32s3_master switched from the old Arduino-ID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
    [config.h]
2026-08-23 feat: LCD display, ESP-NOW reconnect fix, actuator control hardening
    Sensor node (hardware/esp32):
    - Drive a 16x2 I2C LCD (RG1602A-IIC(P)/PCF8574T, SDA=GPIO21 SCL=GPIO22)
    rotating between live T/RH, live NH3, and the master's predicted
    T/NH3 (once its on-device model has warmed up).
    - Extend the ActuatorCommand wire struct with has_prediction/
    predicted_temperature/predicted_ammonia so the master can relay its
    forecast back for display -- purely advisory, no actuation reads it.
    Master node (hardware/esp32s3_master):
    - Fix critical ESP-NOW reliability bug: ensureWifi() called
    esp_now_deinit()/esp_now_init() on every WiFi reconnect, which wipes
    both the registered send/recv callba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
    [config.h, main.cpp]
2026-08-23 refactor(lcd): show current sensor reading only, drop rotation/forecast
    The 16x2 LCD now shows a static two-line readout of this board's own
    live reading -- temp+humidity on row 0, ammonia on row 1 -- redrawn
    whenever a fresh sample completes. Removes the 3-screen rotation timer
    and the "Predicted" screen entirely; the master still relays back
    predicted_temperature/predicted_ammonia/has_prediction on the
    ActuatorCommand wire contract (kept as-is for compatibility), this
    board just no longer displays them.
    Also fixes the LCD_COLS hardcoding in lcdPrintRow found during the
    prior code review (was a literal "%-16s", now "%-*s" driven by
    LCD_COLS so a future display-size change can't silently st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
    [config.h, main.cpp]
2026-08-23 fix(heater-relay): correct inverted ON/OFF polarity
    HEATER_RELAY_ON/OFF were defined assuming an active-LOW relay module
    (LOW = energized/heater ON), but bench testing showed the physical
    heater runs opposite to the commanded state -- checking "heater on" in
    the dashboard turned it off, and vice versa.
    Swapped the two #defines (HEATER_RELAY_ON=HIGH, HEATER_RELAY_OFF=LOW).
    Every call site (applyActuators(), the boot-time OFF initialization)
    already references the symbolic constants rather than raw LOW/HIGH, so
    this one swap in config.h is the complete fix -- no other file
    changes. Updated the stale "active-LOW" comments in main.cpp and the
    README that described the old (wrong) assumption.
    R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
    [config.h, main.cpp]
2026-08-23 fix(master): AUTO safety floor now actually reaches the fan
    ActuatorControl.auto_duty_for_state() in Django has always forced fan
    to 100% on a live CRITICAL_AMMONIA/HEAT_STRESS_WARNING reading -- but
    that number only ever reached real hardware via the MANUAL-mode wire
    path. In AUTO, the master's fanPwm calculation only ever looked at
    pred.ammonia_next (its own forecast), never at classification/state,
    so a live critical reading with a low forecast left the dashboard
    reading "Fan 100%" while the physical fan sat near idle. Confirmed
    live before the fix: real data classified HEAT_STRESS_WARNING with
    predicted_ammonia=4.9ppm (below the 5.0 setpoint) computed fanPwm=0.
    Master now applies the sa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
    [main.cpp]
2026-08-23 feat(sensor): benchmark mode -- scripted synthetic data for testing the predictive system
    Adds a second PlatformIO environment, esp32dev_benchmark, that swaps
    sampleDht()/sampleMq137() for a scripted sequence of scenarios
    (BENCHMARK_SCENARIOS in main.cpp) instead of real sensor reads --
    lets the master's on-device TFLite model, Django's classifier, and
    the real actuator response be exercised on-demand and repeatably,
    without needing a physical sensor attached or waiting on real
    environmental drift. Everything downstream of the sensor read stays
    the genuine pipeline (real ESP-NOW, real inference, real
    classification, real relay/PWM) -- only the read itself is synthetic.
    Compile-time only: BE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
    [config.h, main.cpp]
2026-08-23 fix(sensor): guard LCD init against a boot-loop when unresponsive
    Discovered live while running BENCHMARK_MODE for the first time: the
    physical LCD wasn't responding (loose wire), and lcd.init()'s internal
    I2C writes hung long enough to trip the watchdog and reset the board
    -- which then hit the same hang on the very next boot, forever. Raw
    serial capture confirmed it: the ROM bootloader's "entry 0x..." handoff
    line repeating hundreds of times in seconds, and, with DTR/RTS held
    clean, a full clean boot log that stopped dead right after Wire.begin()
    with no further output for 10+ seconds.
    Fixed by probing LCD_I2C_ADDR with a bounded Wire transaction (50ms
    explicit timeout) BEFORE calling lcd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
    [main.cpp]
2026-08-23 fix(actuator): heater no longer masked by simultaneous critical ammonia
    Real safety gap: classify_environment() returns one mutually-exclusive
    label with ammonia checked first, so a reading that's both cold AND
    above the ammonia critical threshold classifies only as
    CRITICAL_AMMONIA -- never LOW_TEMP_ALERT. Every heater decision in the
    codebase derived directly from that single label
    (state == "LOW_TEMP_ALERT"), so the heater stayed off in exactly the
    case a chick is both gassed and freezing at once. Verified live before
    the fix via direct POST to /api/telemetry/submit/ with
    temperature=10.0, ammonia_level=40.0: predicted_class came back
    CRITICAL_AMMONIA and effective_heater_pct was 0.
    Fixe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
    [main.cpp]
2026-08-26 feat(django): expose flock age_weeks on the control poll endpoint
    The retrained on-device predictive model (see next commit) takes flock
    age in weeks as an input feature (the training pipeline's `week`
    column). The master board already polls /api/telemetry/control/ every
    3s for MANUAL overrides via fetchManualControl() -- reuse that same
    poll instead of adding a second endpoint, by adding a top-level
    age_weeks field to the GET response (not nested under "control", since
    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
2026-08-26 feat(master): retrain predictive model -- flat 44-feature MLP, drop windowed input
    Replaces the old windowed model (19 features, 6-timestep 2D input
    tensor) with a retrained bifurcated multi-task MLP trained against the
    real poultry_sensor_data_cleaned.csv (9,708 rows) and the real training
    script: flat 44-feature vector input (lag/rolling/delta feature
    engineering fully resolved offline, mirrored on-device in
    buildFeatureRow()), two 2-element output heads (next_values regression,
    spike_flags classification for ammonia-spike + temperature-spike).
    Held-out metrics: temperature R2=0.969, ammonia R2=0.841, ammonia-spike
    F1=0.672, temp-spike F1=0.962.
    Training resamples to a fixed 10-minute int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
    [main.cpp]
2026-08-26 fix(classifier): lower reactive ammonia threshold from 25ppm to 15ppm
    AMMONIA_CRITICAL_PPM now matches Table 4-1's "High risk" band start
    (15.0 ppm) instead of sitting 10ppm above it -- previously a reading
    already labeled "High risk" on the dashboard could sit there
    indefinitely without the fan ever reacting, since actuation didn't
    trigger until 25ppm. Now crossing 15ppm immediately flips the state to
    CRITICAL_AMMONIA, which forces the fan to 100% via the existing
    AUTO-mode safety floor (auto_duty_for_state()) -- no new actuation
    path needed, just the one threshold constant.
    Updated everywhere the old 25.0 cutoff was documented or exercised:
    classifier.py's docstring, FlockProfile.custom_a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
    [main.cpp]
2026-08-26 feat(esp32): sensor node drops WiFi entirely -- ESP-NOW only, fixed channel
    The sensor node previously joined the same WiFi AP as the ESP32-S3
    master solely to (a) inherit its channel, since ESP-NOW requires both
    radios on the same one, and (b) sync NTP for the model's hour/month
    features. That's now gone: the sensor node has no WiFi credentials, no
    credentials.h, no AP join, no IP, no NTP -- it only brings the radio up
    (WiFi.mode(WIFI_STA)) and pins it to a fixed channel via
    esp_wifi_set_channel(ESPNOW_WIFI_CHANNEL, config.h) so ESP-NOW can
    still reach the master without ever associating. This actually matches
    the pipeline diagram in the root README and HARDWARE_DOCUMENTATION.md,
    which alre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
    [config.h, main.cpp]
2026-08-26 chore(dashboard): trim redundant nav banner text
    Removed the top-nav subtitle ("Environmental console · House 01 ·
    ESP-NOW sensor node → ESP32-S3 master") and the thresholds paragraph
    under the metric cards ("Heat stress limit > 35.0°C at RH > 70% ·
    Ammonia safety maximum 15.0 ppm") -- both were restating information
    already visible elsewhere on the dashboard (the metric cards, chart
    legends/threshold lines) with no added function.
    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
2026-08-26 fix(actuator): safety floor now overrides MANUAL, not just AUTO
    MANUAL mode's effective_duty() previously returned the operator's raw
    fan_speed_pct/heater_power_pct verbatim, with zero safety checking --
    an operator (or a stale/forgotten MANUAL setting) could leave the fan
    at 0% while ammonia is genuinely critical, or the heater off while
    it's genuinely cold, indefinitely, since nothing would ever override
    it. AUTO already had this exact safety floor; MANUAL never did.
    Fixed by factoring the floor into a shared _apply_safety_floor() used
    by both auto_duty_for_state() and effective_duty()'s MANUAL branch:
    - CRITICAL_AMMONIA or HEAT_STRESS_WARNING -> fan forced to 100%
    - HEAT_STRESS_WARNI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
2026-08-26 docs: fix stale ~45s warm-up claims left over from the model retrain
    HARDWARE_DOCUMENTATION.md's "Master Node Flow" and hardware/esp32/
    README.md's benchmark section still described the OLD windowed
    model's warm-up (~9 samples / ~45s) and the old 3-sample-history/
    6-row-feature-window architecture -- both predate the retrain to the
    current 44-feature bucketed model, which needs 7 finalized 10-minute
    buckets (~70 minutes) before its first prediction, not 45 seconds.
    Also made explicit a real, easy-to-conflate distinction the stale
    wording didn't call out: "10 minutes" appears in two unrelated places
    in this system --
    - the model's forecast HORIZON (predicted_temperature/
    predicted_ammo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
2026-08-26 feat(dashboard): Test Cases tab -- scripted demo reel, zero risk to real system
    Adds a new "Test Cases" tab: one Start button plays an animated,
    precomputed sequence through all 13 named scenarios already used by
    hardware/esp32/src/main.cpp's BENCHMARK_SCENARIOS (ammonia spikes,
    heat stress, cold, combinations), with a live chart of the fed data
    and live readouts of the model's forecast and the resulting fan/heater
    duty -- so fan+heater behavior across many conditions can be shown in
    under 2 minutes, with no 70-minute warm-up wait and no real hardware
    needed.
    Built specifically to satisfy "won't need to alter any code" and
    "don't break the real system":
    - Zero DB writes -- no PoultryTelem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
2026-08-26 fix(esp-now): update hardcoded channel for the new location's router
    Moved to a new location with a different WiFi network. Master's
    credentials.h (gitignored, not in this commit) updated to the new
    SSID/password separately -- this commit is just the channel constant
    both boards need to agree on, since the sensor node hardcodes its
    ESP-NOW channel (see esp32/include/config.h's "Radio" section) rather
    than negotiating one via an AP join.
    Real complication hit along the way: the initially-tried network was
    5GHz-only, which ESP32/ESP32-S3 radios can't join at all (2.4GHz only,
    always). Had to switch to the router's 2.4GHz band SSID instead, which
    also meant a different channel (11, not the pre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
    [config.h]
2026-08-26 feat(dashboard): Test Cases tab now drives the real fan/heater live
    Reworks the just-shipped Test Cases tab from pure simulation into a
    live hardware demo: 13 firmware-mirrored scenarios (animated as smooth
    500ms-per-frame ramps for a chart-only readout) become 6 focused,
    HELD cases -- fan off, fan low (predictive), fan high/sudden spike,
    heater on, heater off, fan+heater together -- each held ~6s (comfortably
    longer than the master's 3s CONTROL_POLL_MS) so the real fan/heater
    actually has time to respond and be seen/heard.
    The reel-computation endpoint (telemetry/ml/reel.py) is UNCHANGED in
    spirit -- still pure computation, no DB writes, same pre-seed-then-
    roll-forward bucket history agai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
2026-08-26 feat(master): log reset reason at boot
    Added to settle a real disagreement rather than keep guessing: the
    model's ~70-minute warm-up kept failing to complete on a long
    unattended run (86+ minutes and still "warming up"), and a
    temporary diagnostic build proved the bucket/feature-counting logic
    itself is correct -- a shrunk-duration test run completed the full
    7-bucket warm-up flawlessly on the first try. That leaves an
    involuntary reboot mid-run as the most likely explanation (each one
    silently wipes model_runner's in-memory bucket history and restarts
    the 70-minute countdown from zero, with no external symptom besides
    "still warming up" taking implausibly long) -- consistent with 8
    network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
    [main.cpp]
2026-08-27 fix(esp-now): update hardcoded channel for another network switch
    The laptop running Django moved to a different WiFi ("amir123",
    channel 1) while the master's credentials.h (gitignored, updated
    separately) still pointed at the previous network -- this produced a
    real, confusing symptom worth documenting: the master booted fine,
    connected to WiFi fine, but UDP discovery broadcast to the wrong
    subnet forever ("No response -- will keep retrying"), because the
    laptop and the master were simply on two different networks. Not a
    code bug -- the discovery mechanism did exactly what it should have;
    it just had nothing to find on that subnet.
    Updated the sensor's hardcoded ESPNOW_WIFI_CHANNEL to mat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
    [config.h]
2026-08-27 fix(dashboard): carry the last real forecast forward instead of blanking
    The model only produces a fresh prediction once per ~10-minute bucket
    (see hardware/esp32s3_master's README "Model architecture" section),
    but the dashboard polls every 5s -- so on ~119 out of every 120 polls,
    latest.predicted_temperature/predicted_ammonia/predicted_spike_probability
    are genuinely null even on a fully warmed-up, actively-predicting
    system. The Overview cards read this the same way they'd read a link
    that had never come up at all: "AI Forecast: pending" / "Master node:
    pending", indistinguishable from the real "nothing has ever arrived"
    case. Confirmed live: watched real predictions land in the DB on
    sch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
2026-08-27 fix(dashboard): find carried-forward forecast in fetched history, not just live ticks
    Follow-up to the previous "carry the last forecast forward" fix --
    that version only ever updated lastForecast from a live poll tick
    that happened to land on a bucket boundary while the page was open.
    A fresh page load or hard refresh starts lastForecast empty and has
    no way to backfill it from a live tick that already happened before
    the page opened, so it kept showing "AI Forecast: pending" even with
    real predictions sitting a few minutes back in the very data the page
    had just fetched. Confirmed live: the API's own historical response
    had a real prediction from 6 minutes prior in-window the whole time.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
2026-08-27 fix(dashboard): forward-fill the chart's forecast line + drop footer clutter
    Same root cause as the metric cards' earlier "pending" bug, just on
    the charts this time: renderCharts() plotted each point's own raw
    predicted_temperature/predicted_ammonia directly, which is null on
    ~119 out of every 120 points (the model only predicts once per
    ~10-minute bucket, points arrive every 5s). With spanGaps:false on
    the forecast dataset, that rendered as an all-but-invisible scatter of
    single dots -- never a visible dashed line, even though real forecasts
    existed the whole time. Same fix pattern as the cards: forward-fill
    each null with the last real forecast value before slicing for the
    current chart w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
2026-08-27 fix(dashboard): flock age dropdown (Table 4-2) + AUTO slider desync
    Two independent UI fixes:
    1. Chick age input was a free-form number (1-52) with no connection to
    the report's actual documented bands -- Table 4-2 only defines
    discrete week 1/2/3/4 bands plus an open-ended "week 5+" band for
    everything older. Replaced with a <select> offering exactly those
    five choices, matching the document instead of allowing arbitrary
    values that mostly just silently collapsed into the same band
    anyway. Handles a real pre-existing edge case: the currently stored
    age_weeks (11, predating this dropdown) has no matching <option> --
    applyProfileToForm() now clamps to 5 so it correctl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
2026-08-27 feat(classifier): heat stress no longer needs humidity, add predictive trigger
    Rationale (from live viva prep on 2026-08-27): watched a real reading of
    36.3C fail to trigger HEAT_STRESS_WARNING because the old rule required
    temperature AND humidity >= 70% together. Chicks' thermoregulation doesn't
    get a pass just because the air is dry -- a hot reading is dangerous on its
    own, especially in the first couple of weeks. Humidity's role (suppressing
    evaporative cooling) is a real effect for mature birds but isn't a
    prerequisite condition here.
    Two changes, both scoped to HEAT_STRESS_WARNING only (ammonia and
    low-temp rules are untouched):
    1. Drop the humidity condition entirely. `classify_envi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
2026-08-28 chore(deploy-prep): sync ESP-NOW channel to ASUS_FC, generate pending migration
    Pre-deployment sweep for the physical PCB move:
    - ESPNOW_WIFI_CHANNEL updated 1 -> 2 in both boards' config.h -- this
    machine is now on "ASUS_FC" (channel 2), not "amir123" (channel 1).
    Reflashed and verified both boards live: master boot log confirms
    "[WIFI] Connected. IP=192.168.2.163 Channel=2", ESP-NOW peer registered,
    sensor packets flowing (seq incrementing, zero gaps), Django discovery
    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
2026-08-28 feat(dashboard): live "next AI update" countdown; sensor node reset-reason parity
    Two independent changes from the same investigation session:
    1. Sensor node is moving off desk USB power onto its own external supply.
    VIN already documented as accepting "USB or external 5V bench supply"
    (hardware/esp32/README.md), so no wiring/firmware change was required
    for that move itself -- but it does mean this board loses the easy
    "just replug it" diagnosis the master already had for silent reboots.
    Ported logResetReason() from the master node verbatim (POWERON/
    BROWNOUT/PANIC/WDT/etc, esp_reset_reason()) so a brownout on a marginal
    external supply is now visible after the fact in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
    [main.cpp]
2026-08-31 chore(dashboard): simplify copy, drop internal jargon from user-facing text
    Wording pass, no behavior change:
    - "AI Forecast"/"Edge-AI forecast" -> "Forecast" throughout -- the AI
    prefix was slapped on every label redundantly; the surrounding context
    (a card literally named "Forecast") already makes clear what it is.
    - "AI spike risk" -> "Spike risk", same reasoning.
    - "Master node: pending" -> "Not available yet" -- this leaked an
    internal architecture term (which physical board the data comes from)
    into a farmer-facing status line; nobody looking at the dashboard needs
    to know there's a "master node" behind it.
    - "System Logs Feed" tab -> "Logs"; "Live console feed" -> "Live acti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
2026-09-05 docs: drop internal PWM/verification PDFs, add final report + presentation decks
    Removes fan_pwm_decision_logic.pdf and live_verification_evidence.pdf
    (internal working docs, no longer needed now that the project is
    finalized). Adds the 81-page minor project report and the proposal +
    final defense presentation decks under docs/.
2026-09-05 hardware: add KiCad schematic & PCB design files for the sensor node
    Checks in the KiCad 9 project for the ESP32 sensor node board
    (kicad.kicad_pro/.kicad_sch/.kicad_pcb/.kicad_prl) alongside the
    existing firmware in hardware/esp32/. Local KiCad backup/autosave
    cruft is gitignored, not committed.
    [kicad.kicad_pcb, kicad.kicad_sch]
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2026-09-05 docs(readme): lead with the project, not the dashboard
    Rewrites the opening to explain the actual minor project -- the
    poultry-farming problem it addresses, the motivation, and the full
    system (sensor node, edge-AI master node, PCB, backend/dashboard) --
    before getting into the technical architecture. The old opening
    paragraph is kept as a 'System at a glance' summary further down.
